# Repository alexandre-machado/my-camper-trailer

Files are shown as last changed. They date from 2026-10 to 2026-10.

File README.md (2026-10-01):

# Trailer Camper

Carretinha de acampamento off-road, inspirada na [Patriot X2 Tourer](https://patriotcampers.com.au/x2n-tourer/)
e na [TerraTrek TTE](https://terratrek.com.au/tte-terra-trek-expedition/), para ser rebocada por um
Jeep Compass Trailhawk 2.0 Diesel 2020.

O projeto é descrito em **Python** e roda no FreeCAD sem interface: cada script gera o modelo 3D,
os arquivos de fabricação para corte a laser (chapa e tubo), a lista de corte e as imagens.

## Vídeo

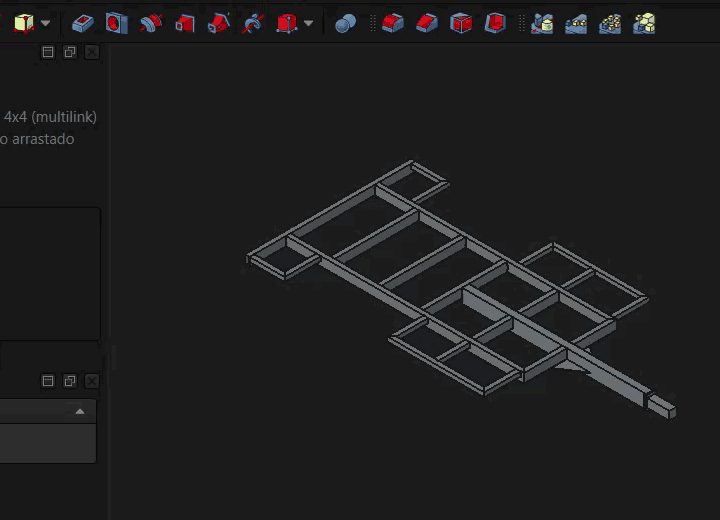
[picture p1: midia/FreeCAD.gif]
Chassi e suspensões girando no FreeCAD


Chassi com as duas opções de suspensão no FreeCAD. Clique na imagem para abrir o [vídeo completo](midia/FreeCAD.mp4).

## Estado atual

- **Chassi** em escada, 2600 mm, longarinas RHS 100x50x3 dobradas 90° na frente (corte em V) até o cambão.
- **Cambão de viga única** RHS 150x75x5, sem "A", para dar mais ângulo de manobra (95°).
- **Encaixe macho-fêmea** em todas as 27 juntas de tubo; quadros laterais com cantos dobrados em V.
- **Duas suspensões em estudo**, no mesmo arquivo e em pastas separadas:
  - agregado multilink traseiro da Fiat Toro 4x4 (pontos ainda estimados);
  - braço arrastado próprio, com mola, amortecedor e cubo de carro 5x110.
- **Pneu** Speedmax Prime Pangea AT 235/65R17, o mesmo do carro (estepe comum).
- **Limites do carro**: 1500 kg com freio, 400 kg sem freio, cerca de 75 kg na bola.

Perfis e espessuras são estimativas para estudo de forma e massa, **não dimensionamento estrutural**.

## Como rodar

Requer FreeCAD 1.1 e o `ezdxf` instalado em `cad/_pylibs` (ver [cad/README.md](cad/README.md)).

```
"C:\Program Files\FreeCAD 1.1\bin\freecadcmd.exe" cad\chassi.py
```

As saídas vão para `cad/out/` (ignorada pelo git, regenerável): `chassi.FCStd`, `chassi.step`,
`laser_tubular/T*.step`, `dxf/*.dxf`, `chassi_lista_corte.csv`, imagens e os `.glb` para o Blender.

Render realista (opcional, Blender 5.2):

```
"C:\Program Files\Blender Foundation\Blender 5.2\blender.exe" --background --python cad\blender_render.py -- cad\out\chassi_braco.glb cad\out\render_braco.png geral
```

## Arquivos

| Arquivo | Conteúdo |
|---|---|
| `cad/veiculo.py` | parâmetros gerais: carro rebocador, pneu, furação, limites de reboque |
| `cad/chassi.py` | chassi, suspensões e rodas; parâmetros no topo |
| `cad/braco.py` | suspensão de braço arrastado: cargas, mola, amortecedor, curso |
| `cad/toro.py` | agregado multilink da Fiat Toro 4x4 |
| `cad/pneu.py` | pneu a partir da medida, com blocos, garras e letras |
| `cad/comum.py` | perfis, tubos com encaixe e dobra em V, lista de corte, DXF, imagens |
| `cad/blender_render.py` | render realista no Blender |
| `cad/bandeja.py` | prova de conceito de chapa dobrada (STEP + DXF planificado) |

Notas técnicas em [cad/README.md](cad/README.md); estado detalhado, decisões e pendências em [CLAUDE.md](CLAUDE.md).

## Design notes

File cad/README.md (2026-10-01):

# CAD → corte a laser (DXF)

## Conceito-chave

O laser corta **2D**. O "DXF 3D" não existe na prática para corte: o que o fornecedor
precisa é a **planificação** (peça desdobrada) de cada chapa, em DXF 2D, escala 1:1, em mm.
Fluxo:

```
modelo 3D paramétrico ──► peça dobrada (STEP, p/ conferir montagem)
                     └──► planificação 2D (DXF) ──► laser ──► dobradeira
```

A planificação depende de dois números **da dobradeira do fornecedor**: raio interno (R)
e fator K. Com os valores errados as abas saem com medida errada. Peça a tabela deles
antes de mandar arquivos definitivos.

## Formato de trabalho recomendado

| Opção | Prós | Contras |
|---|---|---|
| **Python + FreeCAD (Part/OCC) + ezdxf** ← usado aqui | Texto (git, diff, IA edita), paramétrico, gera STEP e DXF do mesmo código, já instalado | Precisa escrever a lógica de planificação (simples para dobras retas) |
| FreeCAD GUI + addon SheetMetal | Visual, desdobra automático (`Unfold` → DXF) | Arquivo `.FCStd` binário, difícil de versionar/automatizar |
| build123d / CadQuery (Python puro) | API moderna, exporta STEP/DXF/SVG | Instalação extra; sem desdobra nativa |
| Onshape (grátis, nuvem) | Sheet metal excelente, exporta DXF pronto | Plano grátis = documentos públicos |
| SVG (Inkscape) → DXF | Bom para peças planas decorativas | Sem unidade/escala confiável, sem 3D |

**Recomendação:** peças de chapa descritas em Python (um arquivo por peça ou família),
o que dá 3D + DXF sempre consistentes. Para montagem geral/visualização, importar os STEP
no FreeCAD (`trailer patriot.FCStd`).

## Regras do DXF para o fornecedor

- 2D, unidade **mm**, escala 1:1, versão R2010 (ou R12 se o software deles for antigo).
- Camada `CORTE`: somente contornos **fechados** (polilinhas/círculos), sem linhas duplicadas.
- Camada `DOBRA`: linhas de dobra (tracejadas) — o laser não corta; às vezes gravam uma marca.
- Camada `INFO`: textos/cotas — **não cortar** (ou mandar em arquivo separado).
- Um arquivo por peça + lista: material, espessura, quantidade, sentido da dobra.
- Furos menores que a espessura da chapa costumam não ser viáveis no laser.
- Alívio de canto nas abas (os cantos recortados) evita rasgo na dobra.

## Prova de conceito: `bandeja.py`

Painel 800×600 com abas de 30 mm, chapa 1,5 mm, furos de fixação e recorte central.

```
"C:\Program Files\FreeCAD 1.1\bin\freecadcmd.exe" cad\bandeja.py
```

Gera em `cad/out/`: `bandeja.step` (3D dobrada), `bandeja.dxf` (planificação),
`bandeja.png` (preview). Imprime tamanho da planificação, metros de corte (base de
orçamento do laser) e massa. Conferência feita: área líquida da planificação × espessura
bate com o volume do sólido 3D (diferença < 0,1%).

`_pylibs/` contém o `ezdxf` instalado localmente para o Python do FreeCAD:
`"C:\Program Files\FreeCAD 1.1\bin\python.exe" -m pip install --target cad\_pylibs ezdxf`
(depois remover a pasta `numpy` de lá — o FreeCAD já tem a dele).

## Parâmetros gerais: `veiculo.py`

Veículo rebocador (Jeep Compass Trailhawk 2.0 Diesel 2020): largura, pneu, furação da roda,
limites de reboque (1500 kg com freio, 400 kg sem freio, ~75 kg na bola) e medidas do engate.
Os scripts importam daqui — trocar o carro é editar um arquivo só.

## Pneu e roda: `pneu.py`

Gera o pneu a partir da medida (`Medida("235/65R17 108H")`: diâmetro, flanco, tala ideal,
carga e velocidade pelos índices) e a roda de aço com a furação. `pneu_at()` imita o Speedmax
Pangea AT das fotos em `pneu/`: 3 fileiras de blocos escalonados por lado (defasadas meio passo),
lamelas em zigue-zague (opcional, lento), garras no ombro alternando longas/curtas e letras em
relevo no flanco externo (+Y). Rodar sozinho gera `out/pneu_*.step` e imagem sombreada (VTK).

## Chassi, suspensão e rodas: `chassi.py` (v0 conceitual)

```
"C:\Program Files\FreeCAD 1.1\bin\freecadcmd.exe" cad\chassi.py
```

Chassi escada (longarinas RHS 100x50x3), cambão de viga única RHS 150x75x5 (entra no
chassi até a travessa do pivô; sem "A" para não limitar a manobra — o script calcula o
ângulo máximo carreta x veículo), balanços até a largura da carroceria (1780), suspensão independente por braço arrastado + mola helicoidal,
pneus 33x12.50R17, furação 6x139,7, bitola 1540. Medidas tiradas por escala do
desenho do X2. Coordenadas: X da traseira para o engate, Y lateral, Z do chão.

Saídas em `cad/out/`: `chassi.FCStd` (peças nomeadas em grupos), `chassi.step`,
`chassi.png` (3 vistas), `chassi_lista_corte.csv` (tubos) e `dxf/` (chapas do laser).
Módulo `comum.py`: perfis, lista de corte, DXF e preview, reaproveitados pelos scripts.

**Perfis são estimativas para estudo de forma e massa, não dimensionamento estrutural.**

### Suspensão: agregado da Fiat Toro 4x4 (`toro.py`)

O `chassi.FCStd` (e o `chassi.step`) traz as **duas suspensões em pastas separadas**, cada uma com
as suas rodas (a bitola muda): "Suspensao Toro 4x4" e "Suspensao braco arrastado", com subpastas
soldado / peças compradas / rodas. Só a opção `SUSPENSAO` abre visível; para alternar, selecionar a pasta
e apertar espaço. Imagens de detalhe: `chassi_suspensao_toro.png` e `chassi_suspensao_braco.png`.

A opção Toro monta o agregado multilink traseiro da Toro 4x4 sob as longarinas
(4 coxins + calços de chapa), com mola separada sob a longarina, amortecedor, braço longitudinal
preso em suporte soldado e cubo/disco 5x110. Dados publicados no cabeçalho de `toro.py`; posições dos
pontos são estimativas a medir.
As chapas só da opção braço saem como `dxf/braco_*.dxf`, e o braço aparece na lista de corte marcado.

### Suspensão de braço arrastado (`braco.py`)

Parâmetros de carga, curso e geometria no topo do arquivo. `analise()` calcula relação de movimento,
rigidez da mola para a frequência alvo, comprimentos da mola e do amortecedor nas três posições
(extensão / estática / compressão) e a altura mínima da caixa de roda; `diagrama()` desenha a vista
lateral do curso (`out/chassi_braco_curso.png`). O resumo sai no terminal ao rodar `chassi.py`.
Pré-dimensionamento para escolher peças e espaço, não cálculo estrutural.

### Encaixe macho-fêmea (laser tubular)

Todo tubo que encosta em outro ganha **linguetas** nas paredes laterais (largura = parede,
altura ≈ 40% do perfil, comprimento = parede do outro tubo + 2 mm), e o tubo que recebe ganha
**rasgos** com 0,25 mm de folga por lado (`Tubo.FOLGA`). As peças se posicionam sozinhas
no gabarito antes da solda. Linguetas que cairiam perto da ponta aberta do outro tubo são omitidas.

- `out/laser_tubular/Txx.step`: um STEP por peça diferente, no eixo X (formato que o
  software de laser tubular importa); códigos e quantidades em `chassi_lista_corte.csv`.
- `out/chassi_encaixes.png`: vista explodida de algumas juntas para conferência.
- Peças espelhadas (longarina direita/esquerda) têm códigos diferentes.

### Cantos dobrados (corte em V + dobra)

As **longarinas** (100x50x3) dobram 90° na frente e viram a travessa dianteira, chegando no cambão com
linguetas: uma peça de ~3008 mm por lado (não cabem as duas na mesma barra de 6 m). A parede dobrada é a de
100 mm de altura, em 3 mm — dobra à mão com alavanca ou no dispositivo do fornecedor.
Os quadros laterais em 50x50 são peças únicas dobradas (`TuboDobrado`): "L" traseiro
(borda + balanço, 1 dobra) e "U" dianteiro (balanço + borda + balanço, 2 dobras).
O laser corta um V de 90° nas paredes de cima, de baixo e na interna; a parede externa fica
inteira, é dobrada e o V fecha numa costura soldada. O STEP é o tubo reto planificado com os V.
Comprimento planificado = soma dos trechos de centro + 2×(b/2 − e) + BA por dobra,
com BA = π/2·K·e e K = 0,33 (`TuboDobrado.K`) — **calibrar dobrando uma peça de teste**.
Só cantos de 90° entre tubos do mesmo perfil, todas as dobras para o mesmo lado.

Confirmar com o fornecedor: folga do rasgo, se querem as linguetas com chanfro de entrada,
e o raio de canto real do tubo (o modelo usa canto vivo e mantém os rasgos afastados ~2×parede dos cantos).

## Visual realista no Blender

O Blender não substitui o FreeCAD (trabalha com malha, não exporta STEP nem DXF exato), mas serve para
imagens realistas. `chassi.py` exporta `out/chassi_toro.glb` e `out/chassi_braco.glb` (uma opção de
suspensão por arquivo), com peças nomeadas e materiais (aço galvanizado, aço bruto, borracha, roda).

- Abrir à mão: Blender > File > Import > glTF 2.0.
- Render automático: `blender_render.py` monta chão, sol e câmera e renderiza com Cycles:

```
"C:\Program Files\Blender Foundation\Blender 5.2\blender.exe" --background --python cad\blender_render.py -- cad\out\chassi_braco.glb cad\out\render_braco.png geral
```

Vistas: `geral`, `tras`, `suspensao`. Junto com o PNG sai um `.blend` pronto para abrir e girar.
Cores e acabamentos ficam em `MATERIAIS` (comum.py).

## Próximos passos

1. Pegar R e K reais com o fornecedor de corte/dobra (e material: aço carbono, galvanizado, alumínio 5052?).
2. Mandar `bandeja.dxf` como teste para validar se o software deles lê sem ajuste.
3. Definir a lista de peças do trailer (painéis laterais, caixas, para-lamas, suportes, reforços do chassi).
4. Generalizar o script: biblioteca com primitivas (aba, dobra em U, furação, recortes) e peças como dados.

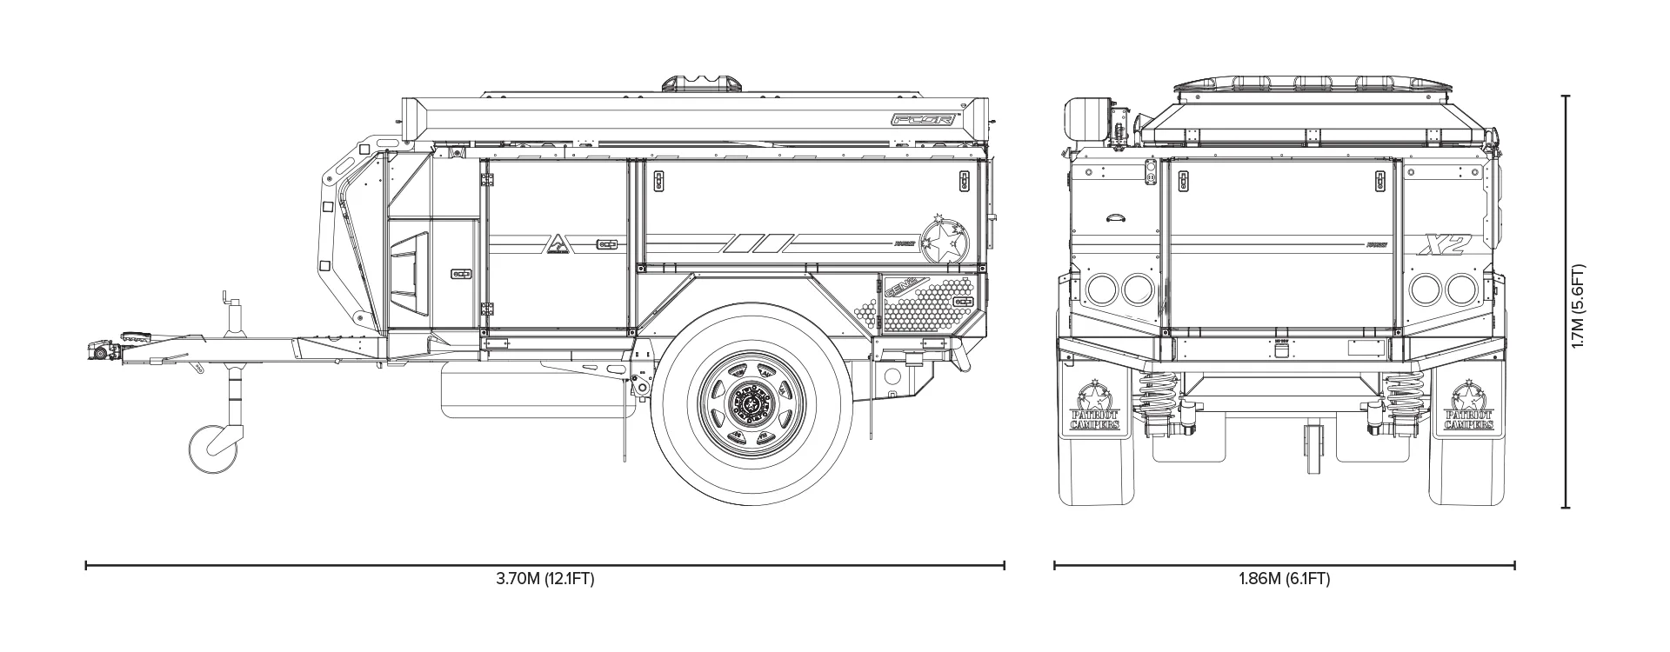
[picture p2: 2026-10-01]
X2 tourer/X2-Tech-Specs-jpg.webp

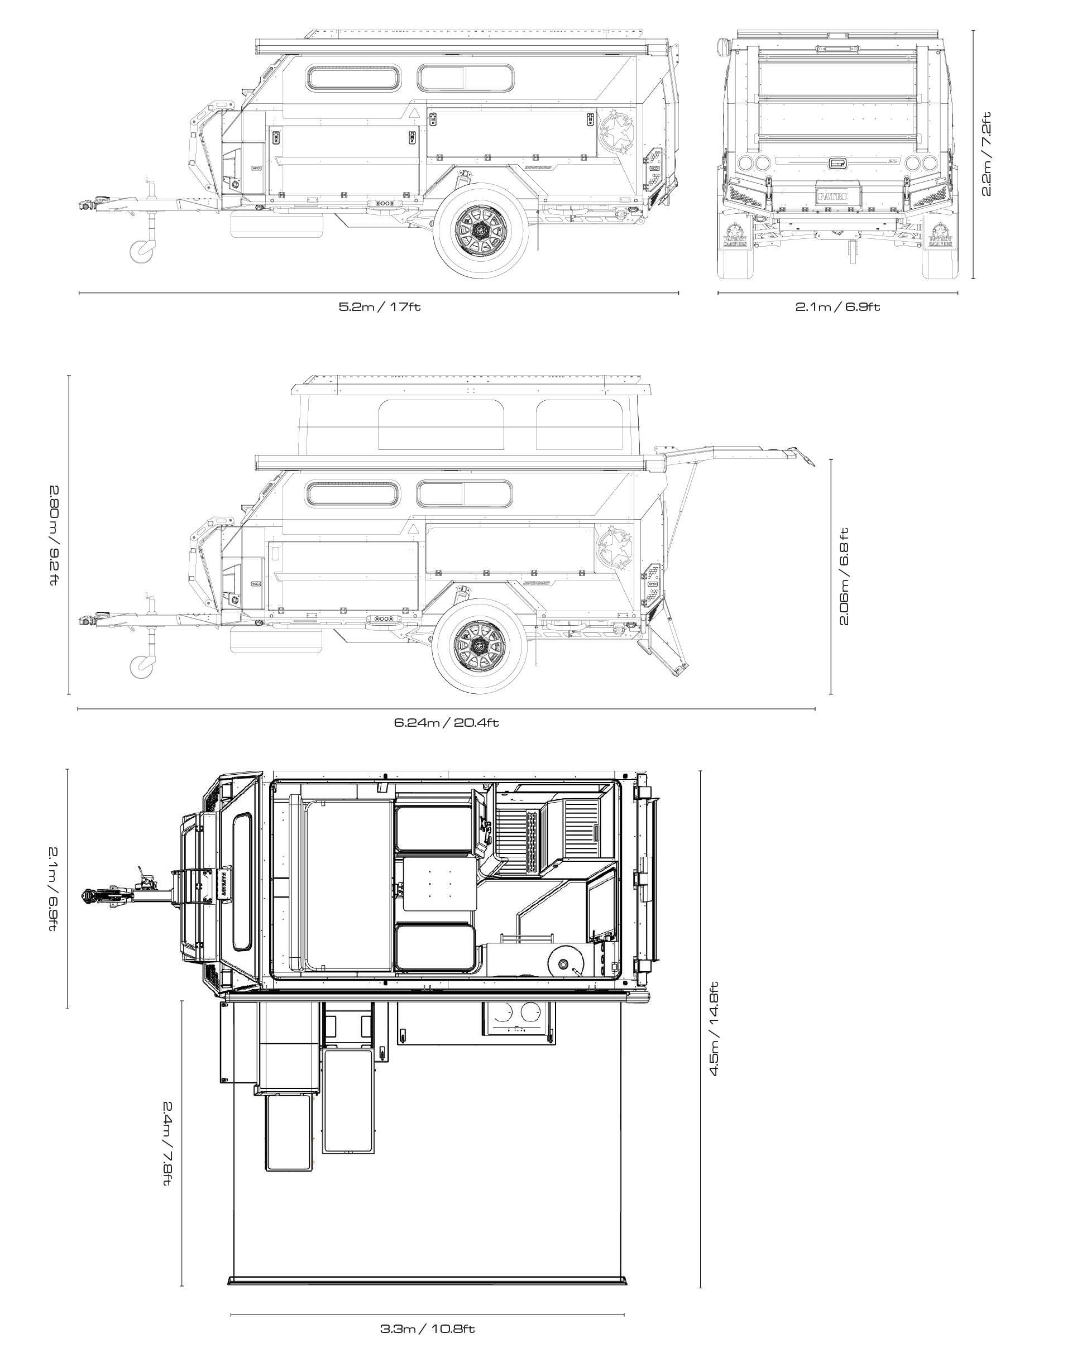
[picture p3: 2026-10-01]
Artboard-1-100-1.jpg

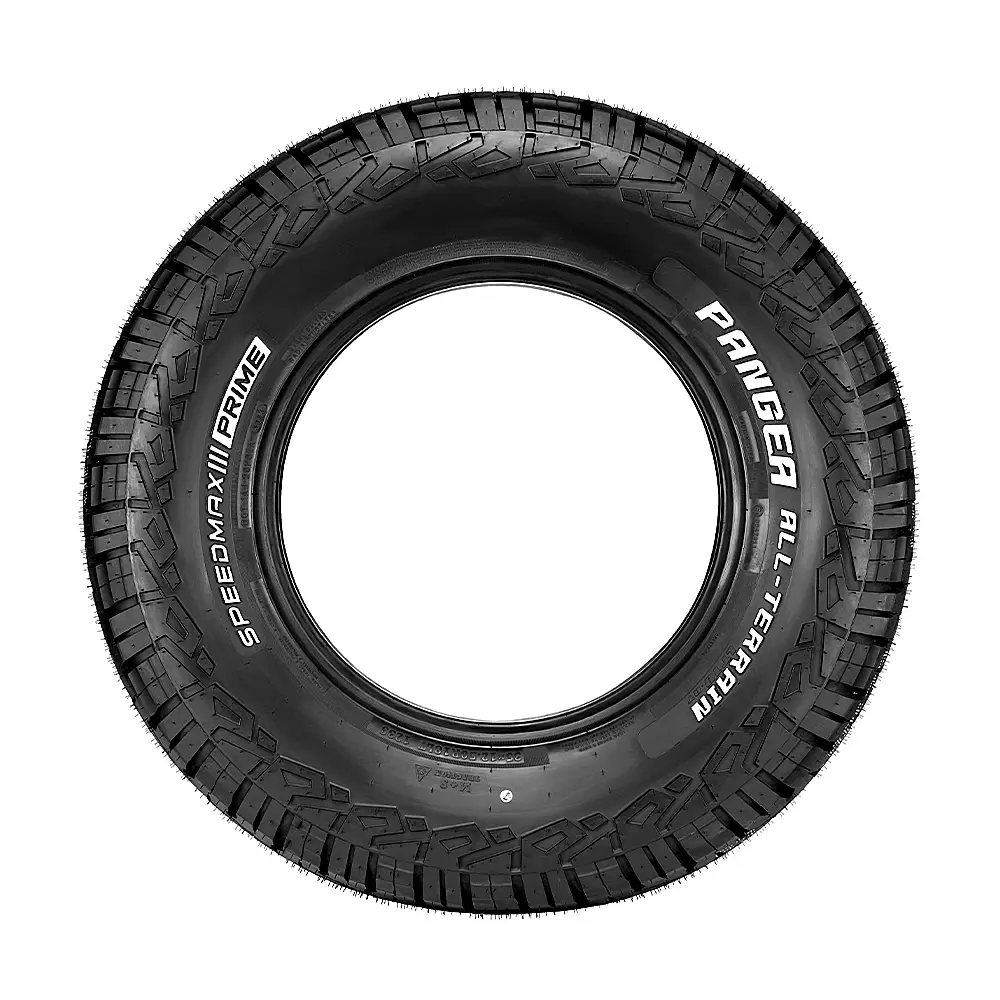
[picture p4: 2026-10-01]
pneu/9669ed2e86ba31eb3f9b.webp

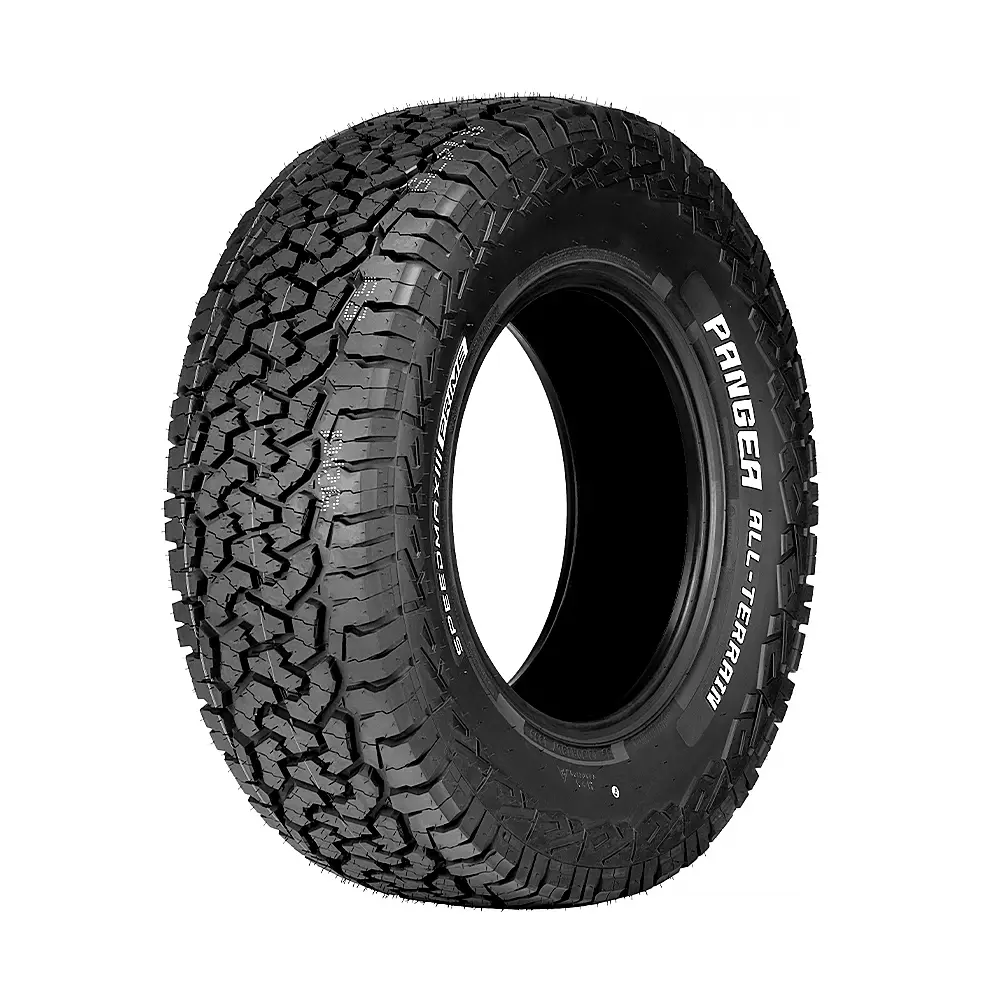
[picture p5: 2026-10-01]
pneu/328ae9fd5db0a0461ec3.webp

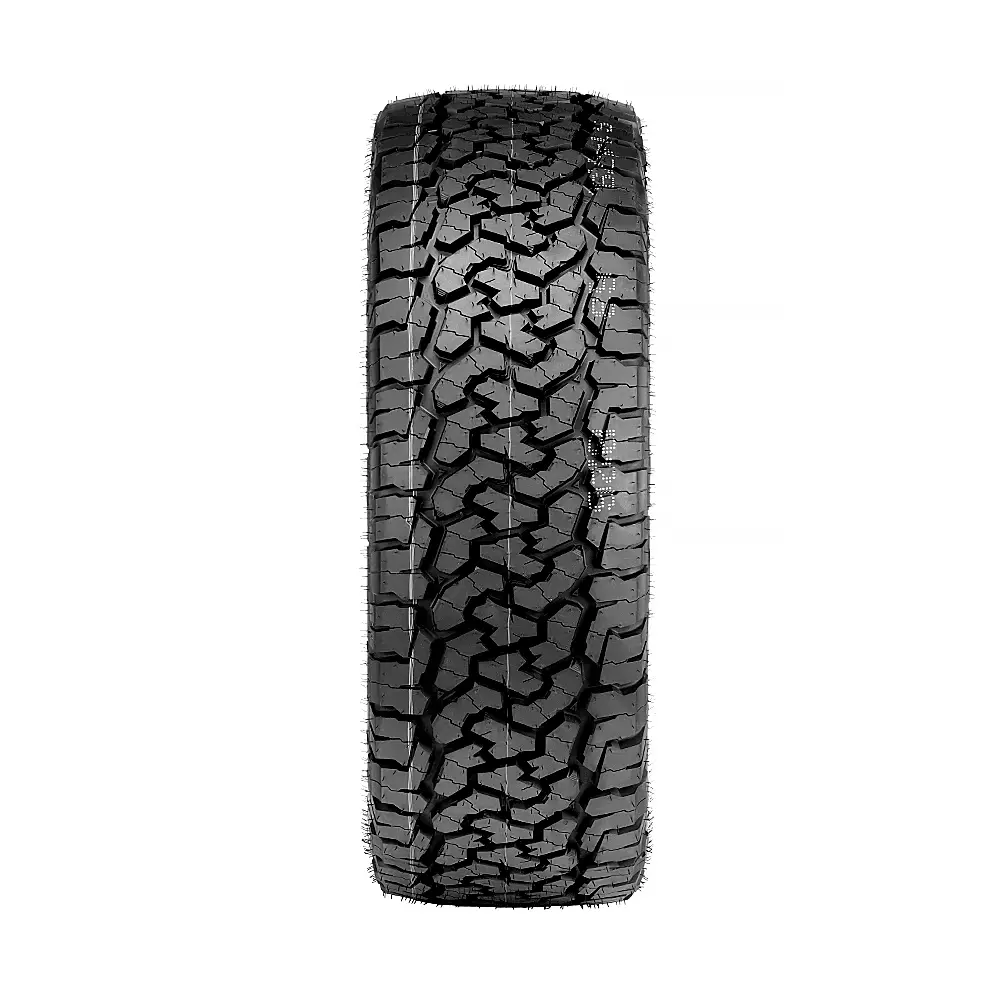
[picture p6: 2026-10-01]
pneu/ebd7b0438fb2508c5823.webp

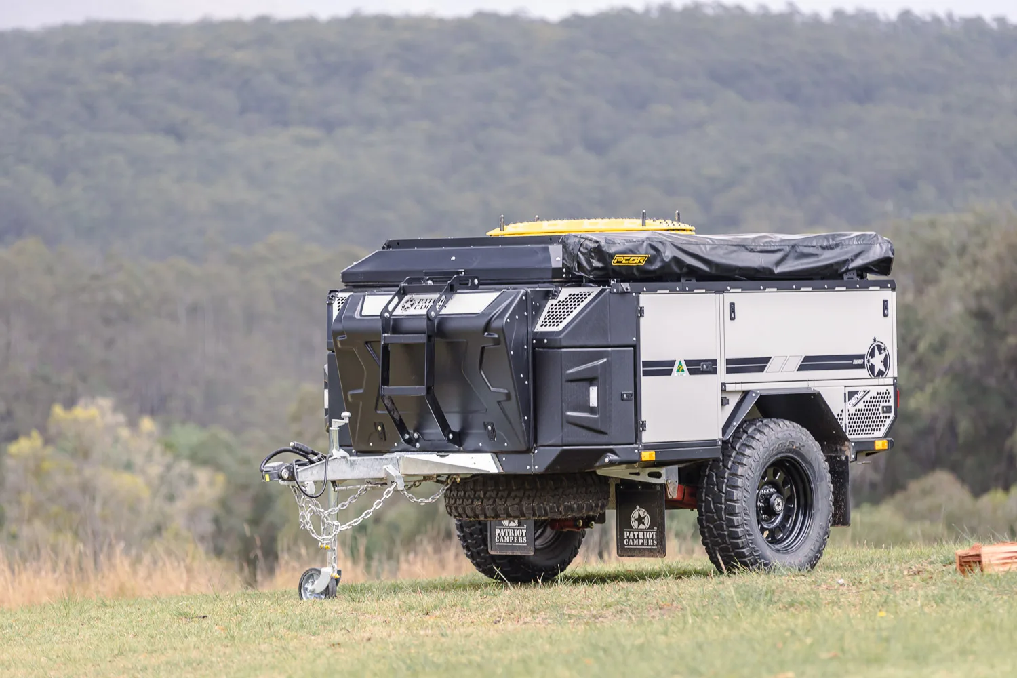
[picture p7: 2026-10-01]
X2 tourer/X2 tourer.webp

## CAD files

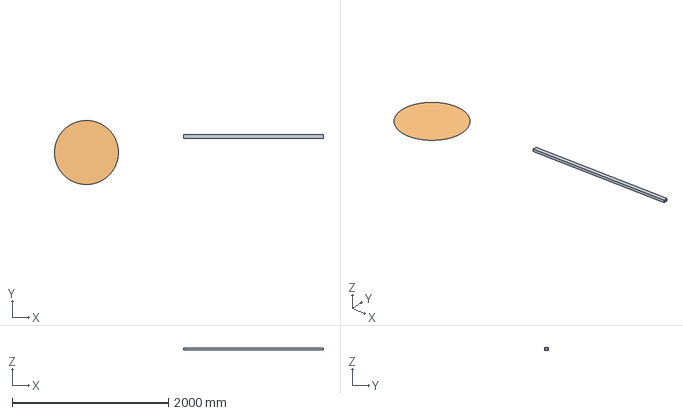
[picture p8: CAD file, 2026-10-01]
trailer patriot.FCStd
3441.1 x 818.9 x 30.0 mm
Column001
Roda

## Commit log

2026-10-01 Commit inicial: carretinha de acampamento off-road
    Projeto de uma carretinha de acampamento similar à Patriot X2 Tourer
    (3,70 x 1,86 x 1,70 m). Inclui imagens de referência, o modelo FreeCAD
    inicial (chassi em tubo RHS 50x30x2.9, roda) e uma prova de conceito
    de peça de chapa paramétrica em Python que gera o 3D (STEP) e a
    planificação em DXF para corte a laser.
    [trailer patriot.FCStd]
2026-10-01 Chassi, suspensão e rodas com encaixe macho-fêmea para laser tubular
    - cad/chassi.py: chassi escada paramétrico (longarinas RHS 100x50x3),
    cambão de viga única RHS 150x75x5 com esquadros (95° de manobra contra
    77° do cambão em A), suspensão independente por braço arrastado + mola
    helicoidal, rodas 33x12.50R17 com furação 6x139,7.
    - Encaixe macho-fêmea em todas as 37 juntas de tubo: linguetas no tubo que
    encosta, rasgos no que recebe; um STEP por peça para o laser tubular.
    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
2026-10-01 Quadros laterais com cantos dobrados (corte em V + dobra)
    - TuboDobrado: peça única com cantos de 90° feitos por V cortado no laser
    tubular e dobra da parede externa; STEP planificado com os V, linguetas
    e rasgos; comprimento desenvolvido com fator K (calibrar em peça de teste).
    - Quadros laterais 50x50: "L" traseiro (1 dobra) e "U" dianteiro (2 dobras).
    Chassi passa de 25 para 17 tubos, 29 juntas, todas com encaixe.
2026-10-01 Pneu AT detalhado, Compass como parâmetro geral e contexto do projeto
    - cad/pneu.py: pneu paramétrico pela medida (235/65R17 108H) imitando o
    Speedmax Prime Pangea AT das fotos em pneu/: blocos escalonados, lamelas,
    garras no ombro e letras em relevo no flanco; roda de aço com a furação.
    - cad/veiculo.py: Jeep Compass Trailhawk 2020 como veículo de referência
    (largura, pneu, furação, limites de reboque e de carga na bola).
    - chassi.py usa o pneu e o carro de veiculo.py; render_3d passa a usar o
    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
2026-10-01 Adiciona suporte para suspensão de braço arrastado (braco.py) com parâmetros de carga, curso e geometria. Atualiza chassi.py para integrar nova suspensão e ajusta toro.py para considerar offset da ro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
2026-10-01 Atualiza documentação em CLAUDE.md e README.md para refletir mudanças na estrutura do chassi e nas longarinas. Ajusta chassi.py para integrar longarinas dobradas e modifica a posição das travessas.
2026-10-01 README na raiz com vídeo e exportação para o Blender
    - README.md: resumo do projeto, link para midia/FreeCAD.mp4, como rodar
    - comum.py: exportar_glb (glTF binário com peças nomeadas e materiais)
    - chassi.py: gera chassi_toro.glb e chassi_braco.glb
    - blender_render.py: render realista sem interface (Cycles), salva PNG + .blend
